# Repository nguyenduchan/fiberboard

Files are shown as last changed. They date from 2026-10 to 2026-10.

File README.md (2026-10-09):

# Fiberboard

Fiberboard là bo mạch điều khiển **logic tích hợp (AIO)**, không có driver stepper Nema. Dùng cho bơm DC, cấp liệu feeder, báo vật thể lạ và mini filler.

Trên bo có **đế cắm ESP32-DevKitC** (nạp phần mềm nhúng qua USB trên module). Nguồn vào **9–24 VDC**. Hai kênh quang **sợi POF 1 mm** (AFBR) gắn trên PCB. Đầu ra relay và van solenoid, **RS485**. Mỗi giắc vào/ra có **đèn SMD 0805** sát cọc. Trong cột nguồn có đèn debug: **D27** sáng khi +24 V sau bảo vệ còn điện, **D25** khi buck ra +5 V, **D6** khi LDO ra 3,3 V. Không có header OLED trên bo.

Kho mã này chỉ chứa thiết kế KiCad và script sinh mạch/layout. **Phần mềm nhúng (firmware)** không có trong kho.

Ghi chú thiết kế chi tiết: [`pcb/DESIGN_NOTES.txt`](pcb/DESIGN_NOTES.txt)

Khối **bảo vệ 24 V + buck** (dùng chung nhiều loại bo): [`pcb/PWR_24V_PROTECT_BUCK_GUIDE.txt`](pcb/PWR_24V_PROTECT_BUCK_GUIDE.txt)

---

## Chức năng các khối

| Khối | Mô tả |
|---|---|
| **MCU** | ESP32-DevKitC trên đế cắm; nạp firmware qua USB trên module |
| **Nguồn** | VIN → **F1/L2/RV1/D7/Q12/C4** → **XL1509** → **+5V**. Mỗi relay lấy +5 V qua ferrite riêng (FB4 / FB5). **AMS1117** → 3,3 V. Chỉ **một** cầu chì F1 tại nguồn tổng 24 V. Mass **NT1+D11+C23+FB3**. Chi tiết: [`pcb/PWR_24V_PROTECT_BUCK_GUIDE.txt`](pcb/PWR_24V_PROTECT_BUCK_GUIDE.txt) |
| **Quang 2 kênh** | Phát AFBR-1624Z + thu AFBR-2624Z mỗi kênh; sợi POF 1 mm cắm trên bo |
| **Đầu vào số** | FOOT (công tắc chân), NPN (cảm biến); cách ly quang PC817 |
| **Đầu ra** | 2 relay G6KU (COM/NO/NC) + 1 van solenoid (MOSFET 24 V); domino J5/J6/J7 (**2EDG5.08**, bước 5,08 mm); flyback D3/D4 (cuộn relay 5 V), D5 SS34 (solenoid trên J7); driver 2N3904 + AO3400A. Tiếp điểm relay kín — tải cảm lớn: snubber/diode tại tải hoặc theo catalog relay |
| **Giao tiếp** | RS485 bán song công (MAX485); **TVS D9/D10** + **R18/R19** trên A/B; LED trạng thái; I2C chỉ trên ESP32 |

Bảo vệ trên bo (tóm tắt): **F1** = đế cầu chì **5×20 mm có nắp** (chân 22,6 mm) tại nguồn tổng 24 V, ống sứ 4 A thay bằng tay, không PPTC SMD; **L2, RV1, D7, C4**; mass **NT1, D11, C23, FB3**; relay **D12/C24**; van lấy **+24V** sau F1. Đèn **Vào / Chì / 24V / 5V / 3V3** chỉ chỗ nguồn đứt. Đầu vào quang PC817; RS485 **D9/D10**. Lắp tủ: nguồn 24 V ≥ 1,5–2 A, dây xoắn, IEC 61000-6-2; dừng khẩn / SIL — phần cứng an toàn riêng.

---

## Đầu nối ra ngoài (I/O)

**Cạnh dài trên** (trái → phải): `J1 | J3 | J4 | F1T | F1R | F2T | F2R` — nguồn vào 24 V, chân, NPN, quang.

**Cạnh dài dưới** (trái → phải): `J5 | J6 | J7 | J2 | J8` — relay 1, relay 2, van, giắc 24 V ra cho bàn phím, rồi RS485. Các giắc giãn trên suốt cạnh; cột relay, van và RS485 rộng hơn để xếp linh kiện trong khung của cọc. Cột trái trong lòng là bảo vệ 24 V, cột kế là buck.

| Ref | Tên | Chân | Ý nghĩa |
|-----|-----|---|---|
| **J1** | VIN | 1 | +9 … +24 VDC |
| | | 2 | Mass domino nguồn |
| **F1T** | Quang 1 phát | POF | Phát; cắm sợi 1 mm thẳng vào mắt hướng ra cạnh bo |
| **F1R** | Quang 1 thu | POF | Thu kênh 1 (cùng chiều cắm như phát) |
| **F2T** | Quang 2 phát | POF | Phát kênh 2 |
| **F2R** | Quang 2 thu | POF | Thu kênh 2 |
| **J3** | FOOT | 1 | Cực A công tắc chân (qua opto) |
| | | 2 | Cực K / mass về |
| **J4** | NPN | 1 | V+ 24 V cho cảm biến hiện trường |
| | | 2 | SIG (tín hiệu NPN) |
| | | 3 | Mass hiện trường (GND_PWR) |
| **J5** | RELAY 1 | 1 / 2 / 3 | COM / NO / NC |
| **J6** | RELAY 2 | 1 / 2 / 3 | COM / NO / NC |
| **J7** | SOLENOID | 1 | +24 V (cực dương cuộn van) |
| | | 2 | SOL− (cực âm; bo cắt mass phía âm) |
| **J2** | Keyboard | 1 / 2 | +24 V đã qua F1 (cùng rail +24V) / mass nguồn. Cấp cho J_PWR mạch keyboard |
| **J8** | RS485 | 1 / 2 / 3 | A / B / mass logic (**2EDG5.08-3P** cái trên bo) |

### Domino hiện trường — **2EDG5.08** (dễ mua Shopee)

| Hạng mục | Khuyến nghị |
|---|---|
| **Trên PCB** | Socket **2EDG5.08** cái, chân ngang 5,08 mm (footprint `Fiberboard:Terminal_2EDG5.08-…`) |
| **Dây ra hiện trường** | **Đầu đực 2EDG** cùng bước (bộ **đực + cái** 2P/3P), siết dây vào đực; hoặc cáp **CH5.08** một đầu + đầu đực 2EDG tùy shop |
| **Tìm mua** | Shopee: `2EDG5.08 3P đực cái thẳng` · `2EDG5.08 2P` · `cáp CH5.08 3P 20cm` (đầu jack — thường gắn thêm đực 2EDG nếu cần) |

### RS485 (J8)

| Hạng mục | Khuyến nghị |
|---|---|
| **Cắm** | **2EDG5.08-3P** đực (giống J4–J6) |
| **Cáp** | Đôi xoắn **2×0,25–0,5 mm²** + bọc chắn; **A/B** chân 1–2, **mass** chân 3; bọc chắn nối mass **một đầu** |
| **Trên bo** | **R15 100 Ω** giữa A–B (điểm cuối bus — termination; gộp mã với R13) |
| **Bố trí** | **J8** ở **cạnh dài dưới** (cùng hàng relay/van), góc phải |

| Ref | Socket trên bo | Dây hiện trường (phổ biến VN) |
|-----|---|---|
| **J1, J3, J7** | 2EDG **2P** cái | Đực **2EDG5.08-2P** + dây 0,5–1,5 mm² |
| **J4, J5, J6, J8** | 2EDG **3P** cái | Đực **2EDG5.08-3P** (+ cáp xoắn có bọc cho RS485) |

Cột I/O tính theo **bề ngang cắm đực 2EDG**, xếp trên **cạnh dài** của hộp 145×90×40.

---

## GPIO ESP32 (tham chiếu firmware)

Tên tín hiệu trong firmware giữ nguyên; cột **Hướng** = vào/ra MCU.

| GPIO | Tín hiệu | Hướng | Ghi chú |
|---|---|---|---|
| IO32 | FIBER1_PWM | Ra | LEDC PWM → phát quang kênh 1 |
| IO33 | FIBER2_PWM | Ra | LEDC PWM → phát quang kênh 2 |
| IO4 | FIBER1_DIG | Vào | TTL từ thu quang kênh 1 |
| IO15 | FIBER2_DIG | Vào | TTL từ thu quang kênh 2 |
| IO25 | IN_FOOT | Vào | Công tắc chân (sau opto) |
| IO26 | IN_NPN | Vào | Cảm biến NPN (sau opto) |
| IO27 | OUT_RLY1 | Ra | Driver relay 1 |
| IO14 | OUT_RLY2 | Ra | Driver relay 2 |
| IO13 | OUT_MOS | Ra | Solenoid |
| IO16 | RS485_RX | Vào | UART RX (MAX485) |
| IO17 | RS485_DE | Ra | DE và RE# (MAX485) |
| IO23 | RS485_TX | Ra | UART TX |
| IO21 | I2C_SDA | Hai chiều | Không ra header bo (tùy chọn ngoài) |
| IO22 | I2C_SCL | Ra | Không ra header bo (tùy chọn ngoài) |

IO32, IO33, IO4, IO15, IO23 và IO16 có điện trở nối tiếp 1 kΩ (R40–R45) trước mắt quang và MAX485.

---

## Thư mục trong kho mã

| Đường dẫn | Vai trò |
|---|---|
| `pcb/fiberboard-logic.kicad_pro` | Dự án KiCad 10 (sơ đồ + PCB) |
| `pcb/DESIGN_NOTES.txt` | Ghi chú nguồn, layout, quang |
| `pcb/PWR_24V_PROTECT_BUCK_GUIDE.txt` | Hướng dẫn khối bảo vệ 24 V và buck (dùng chung) |
| `pcb/BOM.txt` | BOM đầy đủ + bảng **gộp mã** linh kiện cơ bản + giá VND |
| `pcb/ASSEMBLY.txt` | Vùng lắp ráp tùy chọn theo giắc (DNP cả nhóm) |
| `pcb/libraries/` | Symbol và footprint Fiberboard |
| `pcb/scripts/generate_kicad_project.py` | Sinh lại sơ đồ/PCB/thư viện |
| `pcb/scripts/connectivity.py` | Danh sách mạng và kết nối |
| `pcb/scripts/pcb_layout.py` | Vị trí footprint, silk I/O |
| `pcb/scripts/check_pcb_layout.py` | Kiểm tra chồng linh kiện sau khi sinh PCB |
| `pcb/scripts/autoroute.py` | Đi dây tự động (A* trên lưới 0,1 mm, 2 lớp; lõi tăng tốc bằng numba trong `maze_nb.py`): mọi chân ra thẳng ≥0,6 mm rồi mới rẽ; đi dây cả GND/GND_PWR; chân kẹt thì dịch nhẹ linh kiện thụ động (bước 0,25 mm, ≤3 mm, không tạo chồng courtyard mới) và rip-up net chắn đường. Chạy sau `generate_kicad_project.py`: `python pcb/scripts/autoroute.py --passes 7 --png route.png` (~5–6 phút) |

---

## Cách làm việc

| Bước | Việc cần làm |
|---|---|
| 1 | Mở `pcb/fiberboard-logic.kicad_pro` trong KiCad 10 |
| 2 | Sau khi sửa Python: `python pcb/scripts/generate_kicad_project.py` (cần KiCad 10; đường dẫn KiCad trong script) |
| 3 | Đi dây PCB theo ratsnest; refill pour **GND** và **GND_PWR** tại điểm sao **NT1** (cạnh C4) |
| 3b | Sau `generate_kicad_project.py`: `python pcb/scripts/check_pcb_layout.py` — kiểm tra chồng linh kiện. **DRC đỏ “unconnected”** là bình thường khi chưa đi dây (file sinh ra không có track) |

---

## Kích thước bo và vỏ

> **Vỏ:** hộp PLC **145 × 90 × 40 mm** (mã 145T-1D). Giắc nhà máy nằm trên **cạnh dài** (~20 vị trí, pitch 5 mm), không phải hai đầu 90 mm. Lòng thân khoảng **125 × 90 mm**. PCB **118 × 84 mm**.

| Hạng mục | Giá trị |
|---|---|
| **PCB** | 118 × 84 mm |
| **Vỏ** | Hộp PLC ABS 145 × 90 × 40 mm |
| **Giắc** | Cạnh dài trên: J1 nguồn vào, J3 chân, J4 NPN, quang. Cạnh dài dưới: J5/J6 relay, J7 van sát J2 (24 V ra bàn phím), J8 RS485 |
| **Lớp / độ dày** | 2 lớp FR4, 1,6 mm |
| **Lắp ráp** | SMD ưu tiên; domino và AFBR xuyên lỗ theo footprint |
| **Silk mép dưới** | Cột I/O: nhãn tiếng Việt sát giắc cắm, căn giữa ô; chỉnh trong `pcb/scripts/pcb_layout.py` → `IO_LABELS` |

### Ước giá linh kiện (tham chiếu)

Chi tiết từng mã: [`pcb/BOM.txt`](pcb/BOM.txt). Tóm tắt (lẻ VN, 1 bo):

| Hạng mục | Khoảng (k VND) |
|---|---|
| Linh kiện trên PCB (không gồm module ESP32) | ~530 – 1.060 |
| ESP32-DevKitC | ~90 – 185 |
| PCB 2 lớp 118×84 mm | ~25 – 120 |
| **Lắp đủ một máy** | **~645 – 1.365** |

Khối nguồn + cầu chì 5×20: ~165–300k (không relay). Quang AFBR và relay là hai khoản biến động lớn nhất.

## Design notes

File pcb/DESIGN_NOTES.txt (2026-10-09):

Fiberboard logic tích hợp — Ghi chú thiết kế (cấu hình cuối)
==============================================================

Biến thể: logic / feeder / báo / mini filler (không Nema). MCU: đế cắm ESP32-DevKitC-32E (U1, 38 chân).

Tài liệu nguồn + layout: pcb/PWR_24V_PROTECT_BUCK_GUIDE.txt
BOM đầy đủ + giá: pcb/BOM.txt
Lắp ráp DNP theo giắc: pcb/ASSEMBLY.txt

Nguồn và mass
-------------
- VIN J1 9–24 V → F1 (đế 5×20 có nắp, chân 22,6 mm, ống sứ 4 A thay tay) → L2 → RV1/D7 → Q12 → C4 → U2 buck → FB2/C22 → +5V
  → U3/FB1 → +3V3
- Điểm sao mass: NT1 (GND_PWR ↔ GND_SPLICE); D11 + C23; FB3 → GND logic
- Relay: mỗi cọc một group đủ mạch. J5 = FB4 → D12/C24/C25 → K1 (D3, Q3). J6 = FB5 → D26/C26/C27 → K2 (D4, Q4). Xóa một group không cắt nguồn relay còn lại hay phần còn lại của bo. Không cầu chì riêng trên cuộn
- Van: J7 lấy +24V sau F1 (flyback D5); Q5 cắt mass phía âm. Không cầu chì riêng trên van
- Không DC-DC cách ly; đầu vào quang PC817; RS485 TVS D9/D10, R18/R19

Pour mass (đồng)
----------------
- GND_PWR: cột trái (bảo vệ, buck) và giắc trên J1, J3, J4
- GND: cột MCU + hàng dưới bên phải (J2 cấp bàn phím, J5–J7, J8)
- Nối pour: chỉ NT1 (+ D11/C23/FB3 trên sơ đồ)

Layout PCB 118×84 mm (hộp PLC 145×90×40, giắc trên cạnh dài)
----------------------------------------------------------
- Cạnh dài trên: J1 nguồn vào 24 V, J3 chân, J4 NPN, rồi F1T/F1R, F2T/F2R
- Cạnh dài dưới, trái → phải: J5 relay 1, J6 relay 2, J7 van, J2 (24 V ra cho bàn phím), J8 RS485. Giắc giãn trên suốt cạnh; cột group đông linh kiện (relay, van, RS485, opto) rộng hơn cột cọc ít linh kiện.
- Trong lòng, trái → phải: cột **PWR_24V_PROTECT** (F1 đến sao mass, tụ C19/C15/C14 và R17 sát nút lọc) rồi cột **PWR_BUCK** (C16/C17 sát U2, C2/C5 sát ra 5 V, R36–R38 sát chân FB/EN).
- 145T-1D là lỗ 1 phía (khoảng 20P trên một cạnh dài). Hàng ra ở cạnh dài đối diện cần bản lỗ 2 phía hoặc khoét thêm.

I/O
---
- Relay G6KU J5/J6; solenoid J7; FOOT/NPN J3/J4 (opto); RS485 J8 2EDG5.08
- Quang 2 kênh AFBR trên bo; sợi POF 1 mm; C12/C13 lọc nguồn cục bộ
- Flyback: D3/D4 relay 5 V; D5 solenoid 24 V
- Đèn SMD 0805 sát giắc, không thêm GPIO. Nhãn in trên bo: D13 Vào (có điện J1, trước cầu chì); D28 Chì (ngay sau cầu chì, trước L2/Q12); D14 KB (+24 V ra J2); D15 Chân; D16 NPN; D17 RL1; D18 RL2; D19 Van; D20 485; D21–D24 TX1/RX1/TX2/RX2. Debug nguồn trong cột nguồn, nhãn in: D27 24V (sau Q12/C4) tắt thì lỗi trước buck; D25 5V (+5V_RAW cạnh C2) tắt thì buck không ra; D6 3V3 tắt thì LDO không ra. Đọc lỗi nguồn: Vào tắt = mất điện hoặc cắm ngược; Vào sáng + Chì tắt = cầu chì đứt; Chì sáng + 24V tắt = Q12 không thông; 24V sáng + 5V tắt = buck; 5V sáng + 3V3 tắt = LDO. Trở 1 kΩ ở 3,3 V/5 V; 10 kΩ ở 24 V.

GPIO (ESP32)
------------
IO32/33 PWM quang | IO4/15 số | IO25 FOOT | IO26 NPN
IO27/14 relay | IO13 solenoid | IO16/17/23 RS485 | IO21/22 I2C (không header OLED)

Quang 2 kênh (POF 1 mm)
-----------------------
- Phát AFBR-1624Z (F1T/F2T) và thu AFBR-2624Z (F1R/F2R) cùng cạnh dài trên
- IO32/IO33 LEDC → R40/R41 → DATA_IN phát | DATA_OUT thu → R42/R43 → IO4/IO15. IO23/IO16 qua R44/R45 tới DI/RO MAX485.
- C12/C13 100 nF mỗi kênh; không kẹp J2/J11; không khuếch đại ngoài

PCB / vỏ / gia công
-------------------
- Edge.Cuts 118×84 mm (vỏ 145×90×40, lòng thân ~125×90; giắc dọc cạnh 145 mm)
- 2 lớp FR4 1,6 mm; sâu hộp 40 mm — kiểm tra đế + DevKitC không chạm nắp
- Nhãn giắc (tên cổng và chân) và nhãn ý nghĩa đèn in trên F.SilkS. Nhãn nhóm, R/C, MOS, DIN nằm trên F.Fab (thấy trong KiCad, không in). Điện trở hiện "R" + trị số, tụ hiện "C" + trị số trên F.Fab. Nút anode đèn đặt tên *_AN.

Quy trình
---------
1. pcb/fiberboard-logic.kicad_pro
2. python pcb/scripts/generate_kicad_project.py (sau khi sửa script)
3. python pcb/scripts/check_pcb_layout.py
4. Đi dây ratsnest; refill GND / GND_PWR tại NT1 (DRC unconnected trước khi đi dây là bình thường)

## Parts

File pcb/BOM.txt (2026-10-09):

Fiberboard logic — BOM đầy đủ (1 bo)
=====================================
Nguồn sơ đồ: pcb/scripts/connectivity.py | Cập nhật theo đế cầu chì 5×20 có nắp, ống sứ.
Giá VND: lẻ Shopee / LCSC VN, một bộ (±30%), chưa VAT, chưa phí ship. Không gồm ESP32-DevKitC (cắm U1), nguồn 24 V ngoài, dây field, vỏ tủ, gia công PCB/SMT.

Bộ linh kiện cơ bản gộp mã (mua theo cuộn / lốc)
------------------------------------------------
Mục tiêu: hàn tay / SMT lô nhỏ với ít mã SMD thụ động. Số lượng ≈ cho 1 bo (+ dự phòng nhỏ).

| Mã gộp | Giá trị / loại | Số lượng | Ref tiêu biểu | Không gộp được (giữ riêng) |
|---|---|---|---|---|
| R-1k | 1 kΩ 0805 | 22 | R7,R8,R11,R12,R16,R24–R27,R29–R34,R37,R40–R45 | Đèn 3,3 V/5 V, kênh logic, nối tiếp GPIO |
| R-10k | 10 kΩ 0805 | 9 | R9,R10,R14,R22,R23,R28,R38,R39,R46 | R22/R23/R28/R39/R46 đèn 24 V |
| R-100 | 100 Ω 0805 | 2 | R13,R15 | R15: termination RS485 ngắn (≈120 Ω → 100 Ω) |
| R-10 | 10 Ω 0805 | 2 | R18,R19 | RS485 series |
| R-100k | 100 kΩ 0805 | 1 | R17 | Cổng Q12 |
| R-3k | 3 kΩ 0805 | 1 | R36 | FB XL1509 — không đổi |
| C-100n | 100 nF 0805 | 14 | C5,C12–C18,C21,C23,C25,C27 | Gồm C23 ‖ D11; C25/C27 lọc từng relay |
| C-10u25 | 10 µF 0805 ≥25 V | 3 | C16,C19,C7 | Vin 24 V / buck / LDO in |
| C-22u10 | 22 µF 0805 ≥10 V | 1 | C3 | Ra AMS1117 (datasheet) |
| C-elec220 | 220 µF 6,3–10 V radial SMD | 4 | C2,C22,C24,C26 | C24 relay 1, C26 relay 2 |
| C-elec1000 | 1000 µF 25 V | 1 | C4 | |
| D-SS34 | SS34 SOD-123 | 4 | D3,D4,D5,D8 | Flyback + buck |
| D-TVS28 | SMAJ28A SMA | 1 | D7 | VIN |
| D-TVS5 | SMAJ5.0A SMA | 5 | D9–D12,D26 | D12 relay 1, D26 relay 2, RS485, mass |
| FB-BLM | BLM21PG121 0805 | 5 | FB1–FB5 | FB4 relay 1, FB5 relay 2 |
| Q-2N3904 | 2N3904 SOT-23 | 2 | Q3,Q4 | |
| Fuse-holder | Đế 5×20 có nắp, chân 22,6 mm | 1 | F1 | Chỉ nguồn tổng 24 V |
| Fuse-tube | ống sứ 5×20 4 A | 1 | F1 | Thủy tinh F4A lắp được cùng đế |

IC / cơ khí / quang: XL1509, AMS1117, AO4407A, AO3400A, MAX485, PC817×2, G6KU×2, ACM2012, MOV, domino 2EDG, AFBR×4, giá ESP32 — mỗi loại một mã.

Đã chỉnh sơ đồ (connectivity.py) để khớp bảng gộp mã ở trên.

Tóm tắt theo khối
----------------
| Khối | Số dòng linh kiện (loại) | Thấp (k) | Cao (k) |
|---|---|---|---|
| PWR_24V_PROTECT | 16 | 46 | 88 |
| PWR_BUCK | 23 | 53 | 91 |
| J5 + J6 + J7 | 14 | 65 | 120 |
| MCU (chỉ socket U1) | 1 | 18 | 40 |
| Quang 2 kênh | 6 | 220 | 480 |
| Đầu vào FOOT/NPN | 8 | 25 | 45 |
| Relay + domino J5/J6 | 8 | 55 | 100 |
| Solenoid + J7 | 7 | 20 | 38 |
| RS485 + LED + J8 | 8 | 22 | 42 |
| Domino còn lại (J1,J3) | 2 | 6 | 14 |
| **Tổng linh kiện trên PCB** | **~90 chỗ hàn** | **~531** | **~1.063** |
| ESP32-DevKitC (lắp socket, mua riêng) | 1 | 90 | 185 |
| PCB 2L 172×98 mm (5–10 bo) | 1 | 25 | 120 |
| **Tổng lắp 1 máy (có DevKit, có PCB)** | | **~646** | **~1.368** |

Nguồn 24 V ≥ 1,5–2 A (tủ): 150–400k. Ống sứ 5×20 4 A dự phòng (chỉ F1): ~8–20k.

Bảng chi tiết — Nguồn vào & bảo vệ (PWR_24V_PROTECT)
----------------------------------------------------
| Qty | Ref | Giá trị | Footprint / loại | Thấp | Cao | Ghi chú |
|-----|-----|---|---|---|-----|---|
| 1 | J1 | VIN 2EDG5.08-2P | Terminal_2EDG 2P | 3.000 | 8.000 | Socket cái trên bo |
| 1 | F1 | Đế 5×20 có nắp + ống sứ 4 A | Fuseholder_5x20mm_Covered | 8.000 | 18.000 | Đế chân 22,6 mm 5–12k + ống sứ 2–6k |
| 1 | R46 | 10 kΩ | 0805 | 200 | 500 | Đèn Chì, sau cầu chì (gộp R-10k) |
| 1 | D28 | LED Chì | LED 0805 | 500 | 2.000 | Sáng khi còn điện ngay sau F1; tắt trong khi Vào sáng thì cầu chì đứt |
| 1 | L2 | ACM2012 | CM 4 chân SMD | 4.000 | 10.000 | Lọc nhiễu chung |
| 1 | RV1 | MOV ~26 V | Varistor VF | 2.000 | 6.000 | |
| 1 | D7 | SMAJ28A | D_SMA | 1.000 | 3.000 | TVS VIN |
| 1 | C19 | 10 µF 25 V | 0805 | 300 | 1.200 | |
| 1 | C15 | 100 nF | 0805 | 200 | 600 | |
| 1 | Q12 | AO4407A | SOT-23 | 2.000 | 6.000 | P-FET chống ngược |
| 1 | R17 | 100 kΩ | 0805 | 200 | 500 | Cổng Q12 |
| 1 | C4 | 1000 µF 25 V | CP_Elec 10×12,5 | 8.000 | 18.000 | Bulk |
| 1 | C14 | 100 nF | 0805 | 200 | 600 | |
| 1 | R39 | 10 kΩ | 0805 | 200 | 500 | Đèn debug +24 V (gộp R-10k) |
| 1 | D27 | LED 24V | LED 0805 | 500 | 2.000 | Sáng khi +24 V sau bảo vệ còn điện |
| 1 | NT1 | GND_STAR | NetTie-2 SMD | 0 | 1.000 | Pad nối mass |
| 1 | D11 | SMAJ5.0A | D_SMA | 1.000 | 3.000 | Mass GND_PWR↔splice |
| 1 | C23 | 100 nF | 0805 | 200 | 600 | ‖ D11 (gộp mã C-100n) |
| 1 | FB3 | BLM21PG121 | 0805 | 800 | 2.500 | Mass → logic |

Bảng chi tiết — Buck, LDO, nhánh relay (PWR_BUCK)
-------------------------------------------------
| Qty | Ref | Giá trị | Footprint | Thấp | Cao | Ghi chú |
|-----|-----|---|---|---|-----|---|
| 1 | U2 | XL1509-5.0 | TO-263-5 | 8.000 | 18.000 | Buck 24→5 V |
| 1 | C16 | 10 µF | 0805 | 300 | 1.000 | Vin buck |
| 1 | C17 | 100 nF | 0805 | 200 | 600 | |
| 1 | D8 | SS34 | SOD-123 | 400 | 1.200 | |
| 1 | L1 | 47 µH | 1210 | 4.000 | 12.000 | |
| 1 | C2 | 220 µF 6,3–10 V | CP_Elec 6,3×5,4 | 4.000 | 10.000 | Ra buck |
| 1 | C5 | 100 nF | 0805 | 200 | 600 | |
| 1 | R34 | 1 kΩ | 0805 | 200 | 500 | Đèn debug +5V_RAW |
| 1 | D25 | LED 5V | LED 0805 | 500 | 2.000 | Sáng khi buck ra 5 V; tắt thì buck lỗi |
| 1 | R36 | 3 kΩ | 0805 | 200 | 500 | FB U2 |
| 1 | R37 | 1 kΩ | 0805 | 200 | 500 | |
| 1 | R38 | 10 kΩ | 0805 | 200 | 500 | EN |
| 1 | FB2 | BLM21PG121 | 0805 | 800 | 2.500 | +5V_RAW→+5V |
| 1 | C22 | 220 µF | CP_Elec 6,3×5,4 | 4.000 | 10.000 | Rail +5V |
| 1 | U3 | AMS1117-3.3 | SOT-223 | 2.000 | 6.000 | 3,3 V |
| 1 | R16 | 1 kΩ | 0805 | 200 | 500 | Đèn debug +3V3 |
| 1 | D6 | LED 3V3 | LED 0805 | 500 | 2.000 | Sáng khi LDO ra 3,3 V; tắt trong khi D25 sáng thì lỗi LDO |
| 1 | C7 | 10 µF | 0805 | 300 | 1.000 | |
| 1 | C3 | 22 µF | 0805 | 400 | 1.500 | |
| 1 | C18 | 100 nF | 0805 | 200 | 600 | |
| 1 | FB1 | BLM21PG121 | 0805 | 800 | 2.500 | +3V3 |
| 1 | C21 | 100 nF | 0805 | 200 | 600 | |

Dòng tóm tắt PWR_BUCK vẫn tính FB4, D12, C24, C25. Trên bo các ref đó thuộc group J5.

Bảng chi tiết — J5 relay 1 (OPT_J5_RLY1)
------------------------------------------
| Qty | Ref | Giá trị | Footprint | Thấp | Cao | Ghi chú |
|-----|-----|---|---|---|-----|---|
| 1 | J5 | RLY1 2EDG 3P | Terminal 3P | 4.000 | 9.000 | |
| 1 | K1 | G6KU-2F-Y | G6KU-2F_SMD | 22.000 | 45.000 | Relay 1 |
| 1 | Q3 | 2N3904 | SOT-23 | 300 | 800 | Driver K1 |
| 1 | D3 | SS34 | SOD-123 | 400 | 1.200 | Flyback K1 (gộp D-SS34) |
| 1 | R11 | 1 kΩ | 0805 | 200 | 500 | |
| 1 | FB4 | BLM21PG121 | 0805 | 800 | 2.500 | Nhánh +5V_RLY1 |
| 1 | D12 | SMAJ5.0A | D_SMA | 1.000 | 3.000 | TVS nhánh J5 |
| 1 | C24 | 220 µF 6,3–10 V | CP_Elec 6,3×5,4 | 4.000 | 10.000 | Cùng mã C2/C22 |
| 1 | C25 | 100 nF | 0805 | 200 | 600 | |

Bảng chi tiết — J6 relay 2 (OPT_J6_RLY2)
------------------------------------------
| Qty | Ref | Giá trị | Footprint | Thấp | Cao | Ghi chú |
|-----|-----|---|---|---|-----|---|
| 1 | J6 | RLY2 2EDG 3P | Terminal 3P | 4.000 | 9.000 | |
| 1 | K2 | G6KU-2F-Y | G6KU-2F_SMD | 22.000 | 45.000 | Relay 2 |
| 1 | Q4 | 2N3904 | SOT-23 | 300 | 800 | Driver K2 |
| 1 | D4 | SS34 | SOD-123 | 400 | 1.200 | Flyback K2 |
| 1 | R12 | 1 kΩ | 0805 | 200 | 500 | |
| 1 | FB5 | BLM21PG121 | 0805 | 800 | 2.500 | Nhánh +5V_RLY2, cùng đơn giá FB4 |
| 1 | D26 | SMAJ5.0A | D_SMA | 1.000 | 3.000 | TVS nhánh J6, cùng đơn giá D12 |
| 1 | C26 | 220 µF 6,3–10 V | CP_Elec 6,3×5,4 | 4.000 | 10.000 | Cùng mã C24 |
| 1 | C27 | 100 nF | 0805 | 200 | 600 | Cùng mã C25 |

Bảng chi tiết — J7 van (OPT_J7_SOL)
------------------------------------
| Qty | Ref | Giá trị | Footprint | Thấp | Cao | Ghi chú |
|-----|-----|---|---|---|-----|---|
| 1 | J7 | SOL 2EDG 2P | Terminal 2P | 3.000 | 8.000 | |
| 1 | Q5 | AO3400A | SOT-23 | 1.000 | 3.000 | Van |
| 1 | D5 | SS34 | D_SMA | 800 | 2.000 | Flyback van |
| 1 | R13 | 100 Ω | 0805 | 200 | 500 | Cổng Q5 |
| 1 | R14 | 10 kΩ | 0805 | 200 | 500 | Kéo xuống | |

Bảng chi tiết — MCU, quang, tín hiệu (MCU_SIGNAL)
-------------------------------------------------
| Qty | Ref | Giá trị | Footprint | Thấp | Cao | Ghi chú |
|-----|-----|---|---|---|-----|---|
| 1 | U1 | ESP32-DevKitC socket | ESP32_DevKitC_Socket | 18.000 | 40.000 | Chỉ đế; module riêng |
| 1 | R20 | 100 kΩ | 0805 | 200 | 500 | CORE_MCU — kéo IN_FOOT khi không opto J3 |
| 1 | R21 | 100 kΩ | 0805 | 200 | 500 | CORE_MCU — kéo IN_NPN khi không opto J4 |
| 1 | F1T | AFBR-1624Z | AFBR_1624Z_VL | 55.000 | 130.000 | Phát kênh 1 |
| 1 | F1R | AFBR-2624Z | AFBR_2624Z_VL | 55.000 | 130.000 | Thu kênh 1 |
| 1 | F2T | AFBR-1624Z | AFBR_1624Z_VL | 55.000 | 130.000 | Phát kênh 2 |
| 1 | F2R | AFBR-2624Z | AFBR_2624Z_VL | 55.000 | 130.000 | Thu kênh 2 |
| 1 | C12 | 100 nF | 0805 | 200 | 600 | Decap kênh 1 |
| 1 | C13 | 100 nF | 0805 | 200 | 600 | Decap kênh 2 |
| 1 | J3 | FOOT 2EDG 2P | Terminal 2P | 3.000 | 8.000 | |
| 1 | U5 | PC817 | PC817_SO4 | 1.500 | 4.000 | |
| 1 | R7 | 1 kΩ | 0805 | 200 | 500 | |
| 1 | R9 | 10 kΩ | 0805 | 200 | 500 | |
| 1 | J4 | NPN 2EDG 3P | Terminal 3P | 4.000 | 9.000 | |
| 1 | U6 | PC817 | PC817_SO4 | 1.500 | 4.000 | |
| 1 | R8 | 1 kΩ | 0805 | 200 | 500 | |
| 1 | R10 | 10 kΩ | 0805 | 200 | 500 | |
| 1 | U7 | MAX485E | SOIC-8 | 8.000 | 18.000 | |
| 1 | R15 | 100 Ω | 0805 | 200 | 500 | Termination A–B (gộp R-100) |
| 1 | R18 | 10 Ω | 0805 | 200 | 500 | |
| 1 | R19 | 10 Ω | 0805 | 200 | 500 | |
| 1 | D9 | SMAJ5.0A | D_SMA | 1.000 | 3.000 | TVS A (gộp D-TVS5) |
| 1 | D10 | SMAJ5.0A | D_SMA | 1.000 | 3.000 | TVS B |
| 1 | J8 | RS485 2EDG 3P | Terminal 3P | 4.000 | 9.000 | |
| 12 | D13–D24 | LED 0805 | LED_0805 | 500 | 2.000 | Sát giắc J1–J8 và 4 mắt quang; cùng đơn giá D6 |

Linh kiện không hàn (mua kèm khi lắp máy)
-----------------------------------------
| Qty | Mô tả | Thấp | Cao |
|-----|---|---|-----|
| 1 | ESP32-DevKitC-32E (cắm U1) | 90.000 | 185.000 | 38 chân, WROOM-32E, USB trên module |
| 1 | Nguồn 24 VDC 1,5–2 A DIN | 150.000 | 400.000 | Tủ điện |
| 2 | Ống sứ 5×20 4 A dự phòng | 4.000 | 16.000 | Chỉ F1; F4A thủy tinh lắp tạm được |
| 8 | Đầu đực 2EDG field | 20.000 | 50.000 | Theo J1–J8 |
| 2 | Sợi POF 1 mm (tùy chiều dài) | 10.000 | 40.000 | Quang |

Ghi chú đặt hàng
----------------
- SMD 0805/1206, SOIC, SOT: có thể dùng bộ linh kiện rời hoặc SMT JLC (chưa tính trong bảng trên).
- AFBR: giá biến động mạnh; có thể thay footprint tương thích 1629Z/2529Z nếu shop có.
- Tổng **chỉ linh kiện bo** (không DevKit, không PCB): cộng cột Thấp/Cao bảng chi tiết ≈ **531k–1.063k VND**, chưa gồm 12 đèn giắc mới. 12 LED đó cùng đơn giá D6 (0,5–2k) và trở 1 kΩ/10 kΩ đã có trong bảng gộp: thêm khoảng **8k–30k**. D27/R39 debug +24 V nằm trong bảng bảo vệ (0,7–2,5k, đã cộng vào tổng). R40–R45 (6×1 kΩ, cùng đơn giá 200–500) thêm khoảng **1,2–3k**, đã nằm trong dòng R-1k.
- Khối nguồn (protect + buck): ≈ **165k–300k VND** kể cả FB4/D12/C24 từng nằm trong dòng buck. Relay và van tính ở group J5, J6, J7.

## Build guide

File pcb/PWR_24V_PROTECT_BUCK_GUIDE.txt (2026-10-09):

Cấu hình nguồn 24 V + buck + công suất + mass (Fiberboard và tái sử dụng)
===========================================================================
Phiên bản: Fiberboard logic — mức 1 (lọc CM/MOV/tụ giữ áp, không DC-DC cách ly).
Nguồn vào domino 9–24 VDC. Nguồn ngoài: 24 VDC ≥ 1,5–2 A (ray DIN công nghiệp).
Danh sách mạng: pcb/scripts/connectivity.py | Bố trí: pcb/scripts/pcb_layout.py

0. Yêu cầu môi trường (máy dập / băng chuyền) — cấu hình áp dụng
-----------------------------------------------------------------
| Hạng mục | Cấu hình trên bo / tủ |
|---|---|
| Nguồn vào | 9–24 VDC qua J1; nguồn 24 V ≥ 1,5–2 A, có bảo vệ quá dòng |
| Xung nhiễu VIN | F1 đế 5×20 có nắp + ống sứ 4 A (thay tay), L2 lọc CM, RV1 MOV, D7 TVS, C19/C15 tần số cao, Q12 chống ngược, C4 1000 µF giữ áp |
| Mass | Tách GND_PWR / GND logic; nối sao NT1 + D11 ‖ C23 + FB3 (không nhánh mass song song dọc bo) |
| Buck / logic | XL1509 + ferrite FB2; AMS1117 + FB1; không đi dây SW/L1 dưới ESP32 |
| Đầu ra công suất | Mỗi relay một nhánh +5 V (J5: FB4/D12/C24/C25, J6: FB5/D26/C26/C27); van lấy +24V sau F1; flyback D3/D4/D5 |
| Đầu vào hiện trường | Opto PC817 FOOT/NPN (không nối trực tiếp 24 V vào GPIO) |
| RS485 | TVS D9/D10 SMAJ5.0A trên A/B; R15 100 Ω; cáp xoắt + mass; bọc chắn một đầu |
| Vỏ / lắp | Hộp PLC ~179×100×48 mm; PCB 172×98 mm; dây nguồn xoắn; tách cáp motor/biến tần |
| Tham chiếu EMI | IEC 61000-6-2 (bố trí dây, đất vỏ, nguồn) |
| An toàn chức năng | Dừng khẩn, cửa, SIL/PL — phần cứng an toàn riêng (ISO 13849, IEC 60204-1); bo chỉ logic |
| Không có | DC-DC cách ly VIN; không snubber relay trên bo (tải cảm lớn: xử lý tại tải) |

1. Sơ đồ khối điện
------------------
  J1 VIN+ / VIN-
    → F1 đế cầu chì 5×20 mm có nắp (chân 22,6 mm; ống sứ 4 A, thay bằng tay)
    → L2 lọc CM (V+ và mass về domino)
    → RV1 MOV ‖ D7 TVS ‖ C19 (+ C15 tần số cao)
    → Q12 P-FET chống ngược
    → C4 1000 µF 25 V (+ C14 tần số cao)
    → U2 XL1509 → +5V_RAW → FB2 → +5V (+ C22)
    → U3 AMS1117 → FB1 → +3V3

  Mass:
    GND_PWR: mass về domino, buck, cực âm bulk C4, driver relay/van, mass +5V_RLY (cực âm D12)
    GND logic: ESP32, opto, IC RS485, tụ rail logic
    NT1 chân 1 = GND_PWR; NT1 chân 2 = GND_SPLICE
    D11 TVS ‖ C23 100nF: GND_PWR ↔ GND_SPLICE
    FB3: GND_SPLICE → GND (logic)

  Nhánh công suất (dòng nhỏ):
    +5V → FB4 → nhánh J5 (D12, C24/C25, K1)
    +5V → FB5 → nhánh J6 (D26, C26/C27, K2)
    +24V (sau F1) → J7 van (+ D5 flyback)

  Không thuộc khối nguồn (trên bo I/O): opto PC817, TVS RS485 D9/D10, flyback D3/D4 relay.

2. Layout PCB — thứ tự cột (trái → phải)
----------------------------------------
  | PWR_24V_PROTECT | PWR_BUCK | MCU_SIGNAL |

  Cột bảo vệ — hai ô silk, một nhóm KiCad PWR_24V_PROTECT:
    Lọc 24V vào:     F1, L2, Q12, RV1, D7, C19, C15, R17
    Bulk / nối mass*: C4, C14, NT1, D11, C23, FB3

  PWR_BUCK:        U2, L1, D8, C2, C22, U3, C16/C17, C7/C3, FB2, FB1, R36–R38, C5/C18/C21
  Giắc (không còn cột công suất): J5 = FB4, D12, C24/C25, K1 + driver; J6 = FB5, D26, C26/C27, K2 + driver; J7 = Q5 + D5
  MCU_SIGNAL:      U1, U7, U5/U6, linh kiện thụ động RS485, C12/C13
  Đèn debug nguồn: D27 trong cột bảo vệ (+24 V); D25 và D6 trong cột buck (+5V_RAW, +3V3)

  Pour đồng:
    GND_PWR: cột trái đến trước MCU_SIGNAL (bảo vệ + buck) + dải dưới J1/J5–J7
    GND:     cột MCU_SIGNAL + I/O phải (từ LOGIC_X0)
    Nối GND_PWR ↔ GND logic: chỉ tại NT1 (+ D11/C23/FB3 trên mạch sao)

  PCB Fiberboard: 172×98 mm; hàng domino mép dưới: J1 J5 J6 J7 | F1T–F2R J3 J4 J8.

  Thông số script pcb_layout.py (cột bên trong, mm):
    BOARD_W×BOARD_H = 172×98; DIN_RAIL_INSET = 3; INTERIOR_COL_GAP = 1
    PROTECT_COL_W = 34 | BUCK_COL_W = 36 | PWR_OUT_COL_W = 41
    LOGIC_X0 = mép trái cột MCU_SIGNAL; POWER_ZONE_W = LOGIC_X0 − XI0 (pour GND_PWR)
    GROUP_ALIAS: PWR_24V_PROTECT_IN / PWR_24V_PROTECT_BULK → PWR_24V_PROTECT
    Ô silk trong bảo vệ: ~38% chiều cao (vào) / ~48% (bulk/nối mass*)
    FRONT_IO_SPLIT ≈ 66 mm giữa domino nguồn/công suất (J1–J7) và I/O tín hiệu (phải)

2b. I/O tín hiệu và bảo vệ (MCU_SIGNAL — connectivity.py)
---------------------------------------------------------
| Chức năng | Linh kiện / quy tắc |
|---|---|
| FOOT / NPN | U5/U6 PC817; GPIO sau opto IO25/IO26 |
| Driver relay | Q3/Q4 2N3904; cuộn từ +5V_RLY; D3/D4 flyback |
| Solenoid | Q5 AO3400A cắt mass phía âm; J7-1 +24V (sau F1); D5 flyback |
| RS485 | U7 MAX485; D9/D10 SMAJ5.0A; R18/R19; R15 100 Ω; DE/RE IO17 |
| Quang 2 kênh | AFBR-1624Z phát / AFBR-2624Z thu; C12/C13 100 nF/kênh; IO32/33 PWM, IO4/15 số |
| Trạng thái | LED SMD 0805 tại mỗi giắc vào/ra, nhãn in trên bo; D28 Chì sau cầu chì; D27/D25/D6 debug nguồn (24V/5V/3V3) trong cột bảo vệ và buck; không header OLED trên bo |

3. Danh sách linh kiện — bảo vệ 24 V (PWR_24V_PROTECT)
------------------------------------------------------
| Ref | Giá trị | Footprint / ghi chú |
|-----|---|---|
| F1  | Đế 5×20 có nắp + sứ 4 A | Footprint Fuseholder_5x20mm_Covered; chân 22,6 mm; ống sứ nhanh 4 A (thủy tinh F4A lắp được cùng đế) |
| D28 | LED Chì | 0805, sáng khi còn điện ngay sau F1 |
| R46 | 10 kΩ | Hạn dòng D28 |
| L2  | CM ACM2012 | 4 chân, lọc CM |
| RV1 | MOV ~26 V | Varistor VF |
| D7  | TVS SMAJ28A | SMA |
| C19 | 10 µF 25 V | 0805 |
| C15 | 100 nF | 0805 |
| Q12 | AO4407A | SOT-23, high-side |
| R17 | 100 kΩ | 0805, cổng Q12 |
| C4  | 1000 µF 25 V | CP_Elec 10×12,5 |
| C14 | 100 nF | 0805 |
| NT1 | NetTie 2 | Pad1 GND_PWR |
| D11 | TVS SMAJ5.0A | GND_PWR ↔ GND_SPLICE |
| C23 | 100 nF | 0805, song song D11 (gộp mã 100 nF) |
| FB3 | BLM21PG121 | GND_SPLICE → GND logic |

4. Danh sách linh kiện — buck và LDO (PWR_BUCK)
-----------------------------------------------
| Ref  | Giá trị | Ghi chú |
|---|---|---|
| U2 | XL1509-5.0 | TO-263-5; Vin 8–40 V |
| C16  | 10 µF | Vin buck |
| C17  | 100 nF | Vin buck |
| D8 | SS34 | SW → GND_PWR |
| L1 | 47 µH | 1210 |
| C2 | 220 µF 6,3–10 V | Đầu ra buck |
| C5 | 100 nF | Tần số cao 5 V thô |
| R36  | 3 kΩ | FB (XL1509-5.0 cố định 5 V) |
| R37  | 1 kΩ | FB → GND_PWR |
| R38  | 10 kΩ | Kéo EN lên Vin |
| FB2  | BLM21PG121 | +5V_RAW → +5V |
| C22  | 220 µF 6,3–10 V | Sau FB2, rail +5V logic |
| FB4  | BLM21PG121 | +5V → nhánh J5 (đặt tại group J5) |
| U3 | AMS1117-3.3 | SOT-223 |
| C7 | 10 µF | Vào LDO |
| C3 | 22 µF | 3,3 V |
| C18  | 100 nF | Tần số cao 3,3 V |
| FB1  | BLM21PG121 | +3V3 |
| C21  | 100 nF | Sau FB1 |

5. Danh sách linh kiện — theo giắc công suất
--------------------------------------------
Không có group PWR_24V_OUT. Mỗi giắc một group.

J5 (OPT_J5_RLY1): FB4, D12 SMAJ5.0A, C24 220 µF, C25 100 nF, K1, Q3, D3, R11
J6 (OPT_J6_RLY2): FB5, D26 SMAJ5.0A, C26 220 µF, C27 100 nF, K2, Q4, D4, R12
J7 (OPT_J7_SOL):  Q5 AO3400A, D5 SS34, R13 100 Ω, R14 10 kΩ

6. Mạng (net) tham chiếu
------------------------
Tên mạng giữ nguyên trong KiCad; mô tả kết nối:

VIN_RAW:      J1-1 → F1-1
VIN_CM_IN:    F1-2 → L2-1
VIN_CM_RET:   J1-2 → L2-3
VIN_FUSE:     L2-2, D7-1, RV1-1, Q12-2, C15-1, C19-1
GND_PWR:      L2-4, D7-2, RV1-2, C19-2, C15-2, C14-2, C4-2, NT1-1, D11-1, C23-1,
              U2-5, D8-2, mass về buck/LDO công suất, Q3/Q4/Q5 driver, J4-3, D12-2, C24-2, C25-2
GND_SPLICE:   NT1-2, D11-2, C23-2, FB3-1
GND:          FB3-2, MCU, opto, RS485, phía logic C2/C22, tụ +3V3
+24V:         Q12-3, C4-1, C14-1, U2-1, C16/C17, R38, J2-1, J7-1, D5-1 (katốt flyback)
+5V_RAW:      L1-2, C2, C5, FB2-1
+5V:          FB2-2, C22, vào U3, ESP32-19, U7-8, phát quang, FB4-1
+5V_RLY1:    FB4-2, D12, C24/C25, cuộn+ K1, katốt D3
+5V_RLY2:    FB5-2, D26, C26/C27, cuộn+ K2, katốt D4
+3V3:         FB1-2, C21, ESP32, kéo lên opto

7. Quy tắc đi dây PCB
---------------------
- Vòng buck (U2, L1, D8, C2) gọn trong cột PWR_BUCK; không đi SW/L1 dưới hoặc song song U1.
- +5V logic và +5V_RLY: nhánh tách tại FB4; relay không dùng trace +5V chung dài với ESP32.
- Mass về driver relay/van: GND_PWR, đường ngắn trong khung của giắc J5, J6 hoặc J7.
- NT1, D11, C23, FB3: bố trí trong ô bulk/nối mass*; không thêm via nối GND_PWR–GND dọc ranh giới MCU.
- RS485 A/B: đôi xoắt; mass J8; bọc chắn một đầu; không chạy sát cuộn relay tại J5/J6.
- Refill pour GND / GND_PWR sau đi dây; điểm sao duy nhất tại NT1.

8. Cầu chì thay tay (chỉ F1 tại nguồn tổng 24 V)
-----------------------------------------------
- Một đế cầu chì ống **5×20 mm có nắp** gắn PCB, ngay sau J1 (footprint `Fiberboard:Fuseholder_5x20mm_Covered`, chân cách **22,6 mm**). Cao có nắp khoảng 20 mm — vừa hộp 40 mm.
- Mua đế: Shopee `đế cầu chì 5x20 có nắp 22.6` (kiểu PTF-15 / BLX-A có nắp). Đế kẹp hở không dùng.
- Ống: sứ **5×20 4 A nhanh** (Shopee `cầu chì sứ 5x20 4A`). Hết sứ thì ống thủy tinh F4A vẫn lắp cùng đế; nắp mới là thứ giữ ống khi rung.
- Khi đứt: chỉ thay ống; **không** thay PPTC SMD, không hàn lại mạch.
- Không có cầu chì riêng cho relay hay van. Relay và van nằm sau F1.

9. Lắp tủ
---------
- Dây nguồn 24 V xoắn; tách cáp motor/biến tần khỏi domino tín hiệu.
- Vỏ kim loại: nối đất một điểm với GND_PWR (nếu dùng).
- Tham chiếu bố trí EMI: IEC 61000-6-2.
- Dừng khẩn / cửa / SIL: phần cứng an toàn riêng (ISO 13849, IEC 60204-1); bo này chỉ logic.

10. Giá linh kiện (ước lượng, VND)
----------------------------------
BOM đầy đủ từng Ref (đế cầu chì 5×20 có nắp): **pcb/BOM.txt**

| Phạm vi | Thấp | Cao |
|---|---|-----|
| Khối nguồn (protect + buck + D12/C24 + Q5/D5, không relay) | ~165k | ~300k |
| Relay K1/K2 + driver + J5/J6 | ~55k | ~100k |
| Quang AFBR ×4 + decap | ~220k | ~480k |
| MCU socket + I/O + RS485 + domino J1–J8 + LED | ~75k | ~145k |
| **Tổng linh kiện trên PCB** (chưa ESP32 module, chưa PCB) | **~530k** | **~1.060k** |
| + ESP32-DevKitC | +90k | +185k |
| + PCB 2L 172×98 mm (lô nhỏ) | +25k | +120k |
| **Một máy lắp đủ (có DevKit + PCB)** | **~645k** | **~1.365k** |

Nguồn 24 V tủ: ~150k–400k. Giá AFBR và relay chiếm phần lớn biên độ trên.

11. Tệp trong kho Fiberboard
----------------------------
- KiCad: pcb/fiberboard-logic.kicad_pro
- BOM + giá: pcb/BOM.txt
- Sinh lại dự án: python pcb/scripts/generate_kicad_project.py
- Kiểm tra bố trí: python pcb/scripts/check_pcb_layout.py
- Ghi chú bo: pcb/DESIGN_NOTES.txt

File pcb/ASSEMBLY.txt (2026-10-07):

Lắp ráp theo vùng giắc cắm (DNP tùy chọn)
============================================

Mỗi nhóm OPT_* (một giắc) gồm **giắc cái** + linh kiện của giắc đó trong khung chữ nhật sát cọc. Hàng **cạnh dài trên**: J1, chân, NPN, quang. Hàng **cạnh dài dưới**, trái → phải: relay, van, J2 (24 V ra bàn phím), RS485 — giãn ra, cột đông linh kiện rộng hơn. Không còn nhóm công suất chung: cuộn, driver, lọc +5 V và MOSFET van nằm trong group của cọc tương ứng. Bảo vệ 24 V và buck vẫn là hai group nguồn dùng chung.

Bắt buộc (luôn lắp)
-------------------
| Nhóm | Nội dung |
|---|---|
| **CORE_PWR** | J1, J2. Một đèn mỗi giắc: D13 (R22 phía trong), D14 (R23 phía trong) |
| **PWR_24V_PROTECT** | F1, L2, C19, C15, RV1, D7, Q12, R17, C4, C14, đèn D27/R39 (debug +24 V, silk 24V), NT1, D11, C23, FB3 — tụ và trở sát nút chúng lọc |
| **PWR_BUCK** | C16, C17, U2, D8, L1, R36–R38, C2, C5, đèn D25/R34 (debug +5 V, silk 5V), FB2, C22, U3, đèn D6/R16 (debug 3,3 V, silk 3V3), C7, C3, C18, FB1, C21 |
| **CORE_MCU** | U1 (đế ESP32). R20/R21 và R40–R45 (trở nối tiếp GPIO) giữa hai hàng chân đế |

Tùy chọn theo giắc
------------------
| Nhóm | Giắc | Linh kiện phía trên / cùng cột |
|---|---|---|
| **OPT_J3_FOOT** | J3 | Đèn D15 sát giắc (R24 phía trong); U5, R7, R9. **R20** luôn lắp, giữa hai hàng chân đế |
| **OPT_J4_NPN** | J4 | Đèn D16 sát giắc (R25 phía trong); U6, R8, R10. **R21** luôn lắp, giữa hai hàng chân đế |
| **OPT_J5_RLY1** | J5 | Ngay trên cọc: K1, Q3, R11, D3, đèn D17 (R26 phía trong), lọc FB4, D12, C24, C25. Xóa cả group nếu không dùng relay 1 |
| **OPT_J6_RLY2** | J6 | Ngay trên cọc: K2, Q4, R12, D4, đèn D18 (R27 phía trong), lọc FB5, D26, C26, C27. Xóa cả group nếu không dùng relay 2 |
| **OPT_J7_SOL** | J7 | MOSFET Q5 ngay giữa cọc (silk **MOS**), D5 bên cạnh, rồi R13, R14, đèn D19 (R28 phía trong) |
| **OPT_J8_RS485** | J8 | Đèn D20 sát giắc (R29 phía trong); R15, R18, R19, D9, D10. U7 ở dải dưới ESP32 |
| **OPT_FIBER1** | F1T, F1R | Đèn D21, D22 sát mắt (R30, R31 phía trong); C12 |
| **OPT_FIBER2** | F2T, F2R | Đèn D23, D24 sát mắt (R32, R33 phía trong); C13 |
Ghi chú điện
------------
- Không lắp **OPT_J3/J4**: R20/R21 giữ IN_FOOT/IN_NPN ở mức thấp; firmware không đọc hoặc bỏ qua.
- Không lắp **OPT_J8**: không hàn MAX485; UART RS485 trên ESP32 không nối tải.
- Không dùng relay 1: xóa cả group **OPT_J5_RLY1**. Relay 2, buck và MCU không mất nguồn.
- Không dùng relay 2: xóa cả group **OPT_J6_RLY2**. Relay 1 vẫn chạy trên nhánh FB4 riêng.

Trên PCB: khung silk + nhóm KiCad trùng tên nhóm. Danh sách ref: `pcb/scripts/assembly_groups.py`.

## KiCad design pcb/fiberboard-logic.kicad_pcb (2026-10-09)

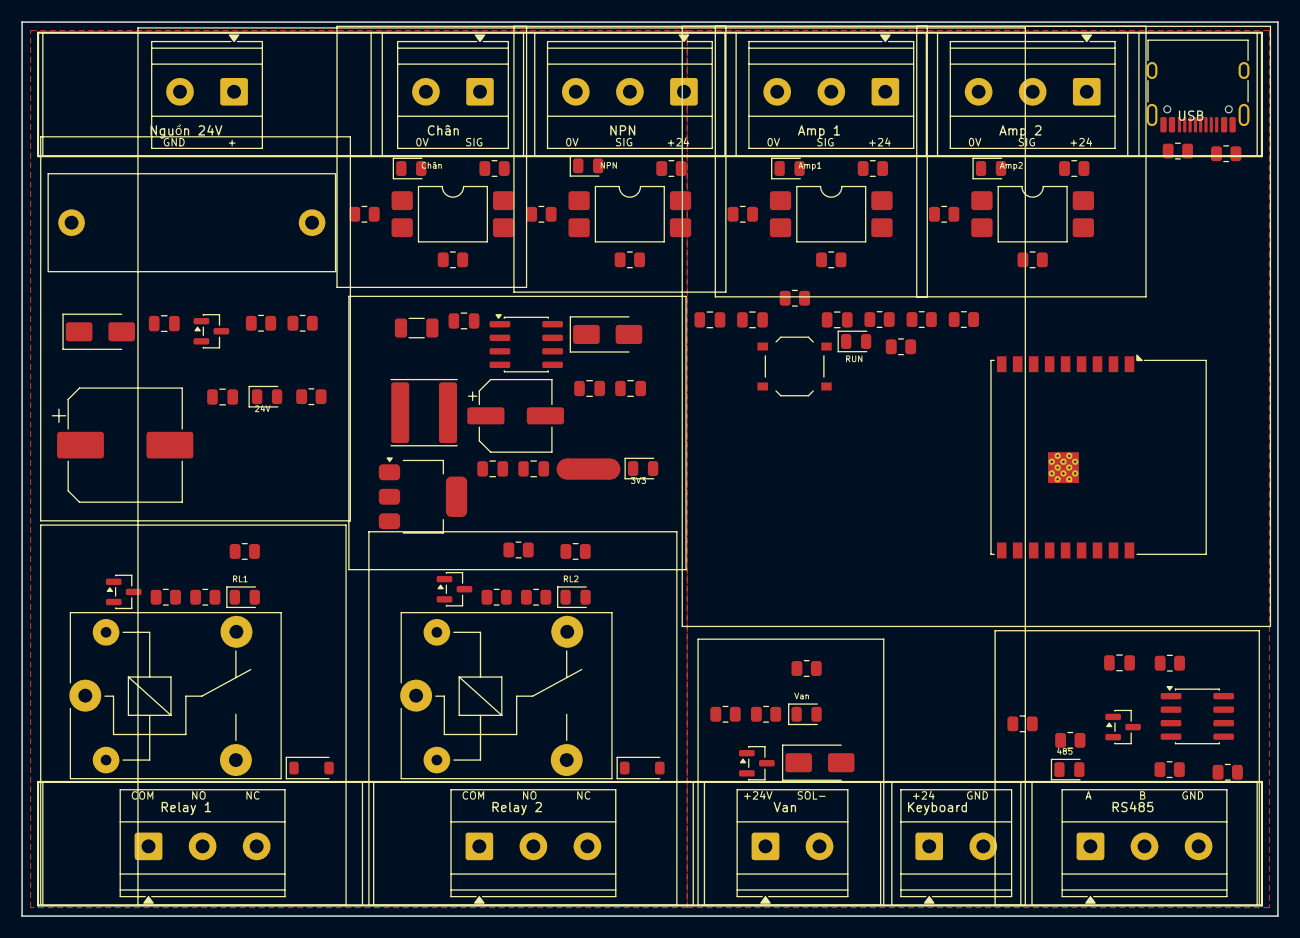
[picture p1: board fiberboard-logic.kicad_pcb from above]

Board: 2 copper layers, 118.0 x 84.0 mm, 97 parts (0 on the bottom side), 62 nets, no tracks yet.

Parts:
C2: 220uF 10V; CP_Elec_6.3x5.4
C3: 22uF; C_0805_2012Metric
C4: 470uF 35V; CP_Elec_10x10.5
C5, C9, C11, C18: 100nF; C_0805_2012Metric
C7, C8: 10uF; C_0805_2012Metric
C10: 1uF; C_0805_2012Metric
C14, C15, C17: 100nF 50V; C_0805_2012Metric
C16: 10uF 50V; C_1206_3216Metric
D3, D4: 1N4148W; D_SOD-123
D5, D8: SS34; D_SMA
D6: 3V3; LED_0805_2012Metric
D7: SMAJ26A; D_SMA
D9: PSM712; SOT-23
D15: FOOT; LED_0805_2012Metric
D16: NPN; LED_0805_2012Metric
D17: RLY1; LED_0805_2012Metric
D18: RLY2; LED_0805_2012Metric
D19: VAN; LED_0805_2012Metric
D20: 485; LED_0805_2012Metric
D27: 24V; LED_0805_2012Metric
D30: RUN; LED_0805_2012Metric
D31: AMP1; LED_0805_2012Metric
D32: AMP2; LED_0805_2012Metric
F1: 5x20 su 4A; Fuseholder_5x20mm_Covered
J1: VIN; Terminal_2EDG5.08-1x02_P5.08mm_Horizontal
J2: KB24; Terminal_2EDG5.08-1x02_P5.08mm_Horizontal
J3: FOOT; Terminal_2EDG5.08-1x02_P5.08mm_Horizontal
J4: NPN; Terminal_2EDG5.08-1x03_P5.08mm_Horizontal
J5: RLY1; Terminal_2EDG5.08-1x03_P5.08mm_Horizontal
J6: RLY2; Terminal_2EDG5.08-1x03_P5.08mm_Horizontal
J7: SOL; Terminal_2EDG5.08-1x02_P5.08mm_Horizontal
J8: RS485; Terminal_2EDG5.08-1x03_P5.08mm_Horizontal
J9: AMP1; Terminal_2EDG5.08-1x03_P5.08mm_Horizontal
J10: AMP2; Terminal_2EDG5.08-1x03_P5.08mm_Horizontal
J11: USB-C; USB_C_Receptacle_HRO_TYPE-C-31-M-12
K1, K2: HF3FF-024-1ZS; Relay_SPDT_SANYOU_SRD_Series_Form_C
L1: 47uH 6045; L_Sunlord_SWPA6045S
NT1: GND_STAR; NetTie-2_SMD_Pad2.0mm
Q3, Q4: MMBT3904; SOT-23
Q5: AO3400A; SOT-23
Q12: AO3401A; SOT-23
R7, R8, R9, R10, R14, R26, R27, R28, R39, R47, R48, R49, R52, R53, R54, R55, R57, R58, R60, R61, R63: 10k; R_0805_2012Metric
R11, R12, R16, R24, R25, R29, R56, R59, R62: 1k; R_0805_2012Metric
R13, R18, R19: 10R; R_0805_2012Metric
R15: 120R; R_0805_2012Metric
R17: 27k; R_0805_2012Metric
R50, R51: 5.1k; R_0805_2012Metric
SW1: BOOT; SW_Push_1P1T_XKB_TS-1187A
U1: ESP32-C3-WROOM-02
U2: XL1509-5.0; SOIC-8_3.9x4.9mm_P1.27mm
U3: AMS1117-3.3; SOT-223-3_TabPin2
U5, U6, U9, U10: LTV-817S; SMDIP-4_W9.53mm
U7: SP3485EN; SOIC-8_3.9x4.9mm_P1.27mm

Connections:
+3V3: C3.1, C8.1, C9.1, C11.1, C18.1, R9.1, R10.1, R16.1, R24.1, R25.1, R52.1, R53.1, R54.1, R55.1, R56.1, R58.1, R59.1, R61.1, R62.1, U1.1, U3.2, U7.8
+5V: C2.1, C5.1, C7.1, L1.2, U2.3, U3.3
+24V: C4.1, C14.1, C16.1, C17.1, D3.1, D4.1, D5.1, J2.1, J4.1, J7.1, J9.1, J10.1, K1.5, K2.5, Q12.2, R7.1, R8.1, R26.1, R27.1, R28.1, R39.1, R57.1, R60.1, R63.1, U2.1
AMP1_AN: R57.2, U9.1
AMP1_SIG: J9.2, U9.2
AMP2_AN: R60.2, U10.1
AMP2_SIG: J10.2, U10.2
BUCK_SW: D8.1, L1.1, U2.2
ESP_BOOT: R55.2, SW1.1, U1.8
ESP_EN: C10.1, R52.2, U1.2
ESP_IO2: R53.2, U1.16
FET_G: Q12.1, R17.1, R63.2
FOOT_AN: R7.2, U5.1
FOOT_SIG: J3.1, U5.2
GND: C3.2, C7.2, C8.2, C9.2, C10.2, C11.2, C18.2, D6.1, D9.3, D20.1, J8.3, J11.A1, J11.A12, J11.B1, J11.B12, J11.SH, NT1.2, R49.2, R50.2, R51.2, SW1.2, U1.9, U1.19, U3.1, U5.3, U6.3, U7.5, U9.3, U10.3
GND_PWR: C2.2, C4.2, C5.2, C14.2, C15.2, C16.2, C17.2, D7.2, D8.2, D27.1, J1.2, J2.2, J3.2, J4.3, J9.3, J10.3, NT1.1, Q3.2, Q4.2, Q5.2, R14.2, R17.2, R47.2, R48.2, U2.4, U2.5, U2.6, U2.7, U2.8
IN_AMP1: D31.1, R58.2, U1.5, U9.4
IN_AMP2: D32.1, R61.2, U1.6, U10.4
IN_FOOT: D15.1, R9.2, U1.3, U5.4
IN_NPN: D16.1, R10.2, U1.4, U6.4
J3_AN: D15.2, R24.2
J4_AN: D16.2, R25.2
J5_AN: D17.2, R26.2
J6_AN: D18.2, R27.2
J7_AN: D19.2, R28.2
J8_AN: D20.2, R29.2
J9_AN: D31.2, R59.2
J10_AN: D32.2, R62.2
LED_RUN: D30.1, R54.2, U1.7
MOS_G: Q5.1, R13.2, R14.1
NPN_AN: R8.2, U6.1
NPN_SIG: J4.2, U6.2
OUT_MOS: R13.1, U1.10
OUT_RLY1: R11.1, U1.18
OUT_RLY2: R12.1, U1.17
P3V3_AN: D6.2, R16.2
P24_AN: D27.2, R39.2
RLY1_B: Q3.1, R11.2, R47.1
RLY1_COIL: D3.2, D17.1, K1.2, Q3.3
RLY1_COM: J5.1, K1.1
RLY1_NC: J5.3, K1.4
RLY1_NO: J5.2, K1.3
RLY2_B: Q4.1, R12.2, R48.1
RLY2_COIL: D4.2, D18.1, K2.2, Q4.3
RLY2_COM: J6.1, K2.1
RLY2_NC: J6.3, K2.4
RLY2_NO: J6.2, K2.3
RS485_A: R18.1, U7.6
RS485_A_BUS: D9.1, J8.1, R15.1, R18.2
RS485_B: R19.1, U7.7
RS485_B_BUS: D9.2, J8.2, R15.2, R19.2
RS485_DE: R29.1, R49.1, U1.15, U7.2, U7.3
RS485_RX: U1.11, U7.1
RS485_TX: U1.12, U7.4
RUN_AN: D30.2, R56.2
SOL_LO: D5.2, D19.1, J7.2, Q5.3
USB_CC1: J11.A5, R50.1
USB_CC2: J11.B5, R51.1
USB_DN: J11.A7, J11.B7, U1.13
USB_DP: J11.A6, J11.B6, U1.14
VIN_FUSE: C15.1, D7.1, F1.2, Q12.3
VIN_RAW: F1.1, J1.1

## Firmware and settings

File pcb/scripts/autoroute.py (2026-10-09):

"""Grid autorouter (classic maze / A* with rip-up-and-retry) for fiberboard-logic.kicad_pcb.

Usage:  python autoroute.py [--pcb FILE] [--png preview.png] [--passes N] [--dry]

Algorithm
  * 0.1 mm Manhattan grid, 2 copper layers (F.Cu prefers horizontal, B.Cu vertical).
  * Every pad first gets a straight *stub* leaving the pad (hand-assembly rule: the
    track runs straight out of the pin for >= STUB_LEN mm before it may turn).
  * Nets are connected pad-by-pad (Prim order) with A* (cost = length + wrong-way +
    bend + via), clearance/width-aware obstacle masks, T-joins on the net's own copper.
  * Failed nets are moved to the front and everything is re-routed (up to --passes).
  * GND / GND_PWR are left to the copper pours; SMD ground pads get stub + stitch via.
  * Result is written back as (segment ...) / (via ...) items; earlier ones are replaced.
"""

from __future__ import annotations

import argparse
import heapq
import math
import re
import sys
import time
import uuid
from dataclasses import dataclass, field
from pathlib import Path

import numpy as np

sys.path.insert(0, str(Path(__file__).resolve().parent))
from pcb_parse import Pad, load_board  # noqa: E402

try:  # compiled search core; pure-Python astar() below is the fallback
    from maze_nb import Maze  # noqa: E402
except ImportError:  # pragma: no cover
    Maze = None

G = 0.1  # grid pitch (mm)
CLR = 0.20  # copper clearance (kicad_pro min_clearance)
CLR_POWER = 0.30
SAFE = 0.03  # extra clearance margin for off-grid stub geometry
EDGE_CLR = 0.45  # copper to board edge
STUB_LENS = (0.6, 0.45, 0.3)  # straight run beyond pad edge, preferred first
STUB_LEN_GND = (0.7, 0.9, 1.2, 1.6, 0.5)
VIA_SIGNAL = (0.6, 0.3)
VIA_POWER = (0.8, 0.4)
GND_NETS = ("GND", "GND_PWR")
KEEPOUT_NET = -999_999
GND_STITCH = False  # True: old behaviour (pads -> stub + via into the pour, no tracks)

# cost model (integers, 10 == one grid step)
C_STEP = 10
C_WRONG = 5
C_BEND = 25
C_VIA = 140
MAX_EXPAND = 500_000  # pure-Python search
MAX_EXPAND_NB = 3_000_000  # numba search
H_WEIGHT = 2.2  # weighted A*: trades optimality for speed

POWER_HI = {
    "+24V", "VIN_RAW", "VIN_FUSE", "SOL_LO",
    "RLY1_COM", "RLY1_NO", "RLY1_NC", "RLY2_COM", "RLY2_NO", "RLY2_NC",
}
POWER_MID = {"+5V", "+3V3", "BUCK_SW"}
# USB-C 16P (bước 0,5 mm): netclass "USB" trong kicad_pro
USB_RULE = {"width": 0.15, "clearance": 0.13, "via": (0.45, 0.2)}


def width_ladder(net: str) -> tuple[float, ...]:
    if net.startswith("USB_"):  # USB-C 0.5 mm pitch pads
        return (USB_RULE["width"],)
    if net in POWER_HI:
        return (0.8, 0.6, 0.4, 0.25)
    if net in POWER_MID or net in GND_NETS:
        return (0.5, 0.4, 0.25)
    return (0.25,)


def via_for(w: float) -> tuple[float, float]:
    return VIA_POWER if w >= 0.5 else VIA_SIGNAL


def clr_for(net: str) -> float:
    if net.startswith("USB_"):
        return USB_RULE["clearance"]
    return CLR_POWER if net in POWER_HI else CLR


# ----------------------------------------------------------------------------- board model
def _crt_overlap(a, c, tol: float = 0.02) -> bool:
    if not a or not c:
        return False
    return min(a[2], c[2]) - max(a[0], c[0]) > tol and min(a[3], c[3]) - max(a[1], c[1]) > tol


@dataclass
class Rect:
    x0: float
    y0: float
    x1: float
    y1: float
    net: int
    kind: str  # pad / smdpad / track / via


@dataclass
class Stub:
    pad: Pad
    layers: tuple[int, ...]  # layers on which the pad can start a route
    ex: float  # exact stub end
    ey: float
    dx: int
    dy: int
    nx: int  # grid node continuing the stub
    ny: int
    direction: int
    length: float
    big: bool = False


class Board:
    def __init__(self, path: str):
        self.text, self.fps, edge = load_board(path)
        self.x0, self.y0, self.x1, self.y1 = edge
        self.W = int(round((self.x1 - self.x0) / G)) + 1
        self.H = int(round((self.y1 - self.y0) / G)) + 1
        self.HW = self.H * self.W
        self.net_id: dict[str, int] = {}
        self.net_name: dict[int, str] = {}
        self.rects: list[list[Rect]] = [[], []]
        self._cache: list[tuple | None] = [None, None]
        self.pads_by_net: dict[str, list[Pad]] = {}
        self.pad_centroid: dict[int, tuple[float, float]] = {}
        self.pour: dict[str, list[list[tuple[float, float]]]] = {}
        self.moved: dict[str, tuple[float, float]] = {}
        self.orig_pos = {f.ref: (f.x, f.y) for f in self.fps}
        # courtyard overlaps already present in the placement (e.g. parts in the ESP32 pocket) stay allowed
        self.orig_overlap = {(a.ref, c.ref) for a in self.fps for c in self.fps
                             if a is not c and _crt_overlap(a.crtyd, c.crtyd)}
        self._load_pads()
        self._load_pours()
        self.static_counts = [len(self.rects[0]), len(self.rects[1])]

    # -- component nudging
    MOVABLE = ("R", "C", "D", "FB", "L", "LED", "Q")
    NUDGE_MAX = 3.0

    def movable(self, fp) -> bool:
        pre = re.match(r"[A-Za-z]+", fp.ref)
        return bool(pre) and pre.group(0) in self.MOVABLE and len(fp.pads) <= 3 and all(p.smd for p in fp.pads)

    def rebuild_static(self) -> None:
        tracks = [self.rects[L][self.static_counts[L]:] for L in (0, 1)]
        self.rects = [[], []]
        self._cache = [None, None]
        self.pads_by_net = {}
        self._load_pads()
        self.static_counts = [len(self.rects[0]), len(self.rects[1])]
        for L in (0, 1):
            self.rects[L].extend(tracks[L])

    def move_fp(self, fp, dx: float, dy: float) -> None:
        fp.x += dx
        fp.y += dy
        if fp.crtyd:
            x0, y0, x1, y1 = fp.crtyd
            fp.crtyd = (x0 + dx, y0 + dy, x1 + dx, y1 + dy)
        for p in fp.pads:
            p.x += dx
            p.y += dy
        self.moved[fp.ref] = (fp.x - self.orig_pos[fp.ref][0], fp.y - self.orig_pos[fp.ref][1])
        self.rebuild_static()

    def fp_gap_ok(self, fp, gap: float = 0.35) -> bool:
        """Moved footprint keeps `gap` between its pads and every other footprint's pads, and the board edge."""
        for o in self.fps:
            if o is not fp and (fp.ref, o.ref) not in self.orig_overlap and _crt_overlap(fp.crtyd, o.crtyd):
                return False
        for p in fp.pads:
            if (p.x - p.w / 2 < self.x0 + 1.0 or p.x + p.w / 2 > self.x1 - 1.0
                    or p.y - p.h / 2 < self.y0 + 1.0 or p.y + p.h / 2 > self.y1 - 1.0):
                return False
            for o in self.fps:
                if o is fp:
                    continue
                for q in o.pads:
                    if abs(q.x - p.x) > 6 or abs(q.y - p.y) > 6:
                        continue
                    ddx = max(q.x - q.w / 2 - (p.x + p.w / 2), p.x - p.w / 2 - (q.x + q.w / 2), 0.0)
                    ddy = max(q.y - q.h / 2 - (p.y + p.h / 2), p.y - p.h / 2 - (q.y + q.h / 2), 0.0)
                    if math.hypot(ddx, ddy) < gap:
                        return False
        return True

    def apply_moves(self, text: str) -> str:
        for ref, (dx, dy) in self.moved.items():
            if abs(dx) < 1e-9 and abs(dy) < 1e-9:
                continue
            k = text.find(f'(property "Reference" "{ref}"')
            f0 = text.rfind("	(footprint ", 0, k)
            m = re.compile(r"\(at ([-\d.]+) ([-\d.]+)( [-\d.]+)?\)").search(text, f0)
            nx, ny = float(m.group(1)) + dx, float(m.group(2)) + dy
            text = text[:m.start()] + f"(at {nx:.4f} {ny:.4f}{m.group(3) or ''})" + text[m.end():]
        return text

    # -- nets
    def nid(self, name: str) -> int:
        if name not in self.net_id:
            i = len(self.net_id) + 1
            self.net_id[name] = i
            self.net_name[i] = name
        return self.net_id[name]

    def _load_pads(self) -> None:
        anon = -1
        for fp in self.fps:
            cx = sum(p.x for p in fp.pads) / max(1, len(fp.pads))
            cy = sum(p.y for p in fp.pads) / max(1, len(fp.pads))
            fp.pads = [p for p in fp.pads if any(l in ("F.Cu", "B.Cu", "*.Cu") for l in p.layers)]  # drop paste-only apertures
            for ko in fp.keepouts:  # e.g. ESP32 antenna: no copper of any net
                for L in (0, 1):
                    self.add_rect(L, *ko, KEEPOUT_NET, "keepout")
            for p in fp.pads:
                self.pad_centroid[id(p)] = (cx, cy)
                if p.net:
                    n = self.nid(p.net)
                    self.pads_by_net.setdefault(p.net, []).append(p)
                else:
                    n = anon
                    anon -= 1
                lays = self.pad_layers(p)
                for L in lays:
                    self.add_rect(L, p.x - p.w / 2, p.y - p.h / 2, p.x + p.w / 2, p.y + p.h / 2, n,
                                  "smdpad" if p.smd else "pad")

    @staticmethod
    def pad_layers(p: Pad) -> tuple[int, ...]:
        if any(l in ("*.Cu",) for l in p.layers) or (not p.smd):
            return (0, 1)
        if "B.Cu" in p.layers and "F.Cu" not in p.layers:
            return (1,)
        return (0,)

    def _load_pours(self) -> None:
        for m in re.finditer(r'\(zone\s+\(net \d+\)\s+\(net_name "([^"]+)"\)\s+\(layer "([^"]+)"\)(.*?)\(polygon\s+\(pts(.*?)\)\s*\)',
                             self.text, re.S):
            name, layer, _, pts = m.groups()
            poly = [(float(a), float(b)) for a, b in re.findall(r"\(xy ([-\d.]+) ([-\d.]+)\)", pts)]
            self.pour.setdefault(name, []).append(poly)

    def in_pour(self, net: str, x: float, y: float, margin: float) -> bool:
        for poly in self.pour.get(net, []):
            xs = [p[0] for p in poly]
            ys = [p[1] for p in poly]
            if min(xs) + margin <= x <= max(xs) - margin and min(ys) + margin <= y <= max(ys) - margin:
                return True  # pours here are axis-aligned rectangles
        return False

    # -- rect store
    def add_rect(self, layer, x0, y0, x1, y1, net, kind) -> None:
        self.rects[layer].append(Rect(x0, y0, x1, y1, net, kind))
        self._cache[layer] = None

    def arrays(self, layer: int):
        if self._cache[layer] is None:
            r = self.rects[layer]
            a = np.array([[q.x0, q.y0, q.x1, q.y1, q.net] for q in r], dtype=float).reshape(-1, 5)
            self._cache[layer] = a
        return self._cache[layer]

    def exact_clear(self, layer, rx0, ry0, rx1, ry1, net, clr) -> bool:
        a = self.arrays(layer)
        if not len(a):
            return True
        m = a[:, 4] != net
        dx = np.maximum(np.maximum(a[:, 0] - rx1, rx0 - a[:, 2]), 0.0)
        dy = np.maximum(np.maximum(a[:, 1] - ry1, ry0 - a[:, 3]), 0.0)
        d = np.hypot(dx, dy)
        if np.any(d[m] < clr - 1e-9):
            return False
        # board edge
        return (rx0 >= self.x0 + EDGE_CLR - 1e-9 and ry0 >= self.y0 + EDGE_CLR - 1e-9
                and rx1 <= self.x1 - EDGE_CLR + 1e-9 and ry1 <= self.y1 - EDGE_CLR + 1e-9)

    # -- grid masks
    def build_masks(self, net: int, netname: str, w: float, vd: float):
        """Return (track_blocked[2], via_blocked) as uint8 H*W arrays."""
        c = clr_for(netname) + SAFE
        H, W = self.H, self.W
        mt = [np.zeros((H, W), np.uint8), np.zeros((H, W), np.uint8)]
        mv = [np.zeros((H, W), np.uint8), np.zeros((H, W), np.uint8)]
        for L in (0, 1):
            for r in self.rects[L]:
                own = r.net == net
                if own and r.kind != "smdpad":
                    continue
                if own:  # never drop vias onto own SMD pads (hand soldering)
                    dv = vd / 2 + 0.12
                    self._paint(mv[L], r, dv)
                    continue
                cc = max(c, clr_for(self.net_name.get(r.net, "")) + SAFE)
                self._paint(mt[L], r, w / 2 + cc)
                self._paint(mv[L], r, vd / 2 + cc)
            for m, half in ((mt[L], w / 2), (mv[L], vd / 2)):
                e = EDGE_CLR + half
                n = int(math.ceil(e / G)) + 1
                m[:n, :] = 1
                m[-n:, :] = 1
                m[:, :n] = 1
                m[:, -n:] = 1
        via_bad = (mv[0] | mv[1]).astype(np.uint8)
        return [m.ravel().tobytes() for m in mt], via_bad.ravel().tobytes()

    def _paint(self, m: np.ndarray, r: Rect, d: float) -> None:
        i0 = int(math.floor((r.x0 - self.x0 - d) / G + 1e-9)) + 1
        i1 = int(math.ceil((r.x1 - self.x0 + d) / G - 1e-9)) - 1
        j0 = int(math.floor((r.y0 - self.y0 - d) / G + 1e-9)) + 1
        j1 = int(math.ceil((r.y1 - self.y0 + d) / G - 1e-9)) - 1
        if i1 < 0 or j1 < 0 or i0 >= self.W or j0 >= self.H:
            return
        m[max(j0, 0): j1 + 1, max(i0, 0): i1 + 1] = 1

    # -- coordinates
    def cell_xy(self, i: int) -> tuple[float, float]:
        return self.x0 + (i % self.W) * G, self.y0 + (i // self.W) * G

    def xy_cell(self, x: float, y: float) -> int:
        return int(round((y - self.y0) / G)) * self.W + int(round((x - self.x0) / G))


# ----------------------------------------------------------------------------- stubs
DIRS = [(1, 0), (0, 1), (-1, 0), (0, -1)]  # E S W N  (y grows downward)


def _dir_index(dx: int, dy: int) -> int:
    return DIRS.index((dx, dy))


def stub_candidates(b: Board, p: Pad, mt: list[bytes] | None) -> list[tuple[int, int]]:
    cx, cy = b.pad_centroid[id(p)]
    vx, vy = p.x - cx, p.y - cy
    sx = (1 if vx >= 0 else -1)
    sy = (1 if vy >= 0 else -1)
    long_h, long_v = p.w > p.h * 2.0, p.h > p.w * 2.0
    if long_h:
        order = [(sx, 0), (0, sy), (0, -sy), (-sx, 0)]
    elif long_v:
        order = [(0, sy), (sx, 0), (-sx, 0), (0, -sy)]
    elif abs(vx) >= abs(vy):
        order = [(sx, 0), (0, sy), (0, -sy), (-sx, 0)]
    else:
        order = [(0, sy), (sx, 0), (-sx, 0), (0, -sy)]
    if not p.smd and not (long_h or long_v):
        # through-hole: prefer the direction with the longest free run (outward on ties)
        def run(d):
            n = 0
            x, y = p.x, p.y
            half = (p.w if d[0] else p.h) / 2
            for k in range(1, 40):
                xx, yy = x + d[0] * (half + k * G), y + d[1] * (half + k * G)
                if not b.exact_clear(0, xx - 0.125, yy - 0.125, xx + 0.125, yy + 0.125, b.nid(p.net) if p.net else -999, CLR + SAFE):
                    break
                n = k
            return min(n * G, 1.0)
        order.sort(key=lambda d: -run(d))
    return order


def pick_stub(b: Board, p: Pad, lens=STUB_LENS, w: float = 0.25, mt=None) -> Stub | None:
    net = b.nid(p.net)
    c = clr_for(p.net) + SAFE
    lays = b.pad_layers(p)
    for d in stub_candidates(b, p, None):
        half = (p.w if d[0] else p.h) / 2
        for ln in lens:
            ex = p.x + d[0] * (half + ln)
            ey = p.y + d[1] * (half + ln)
            # snap along-axis coordinate to the grid so the route continues on-grid
            # (round away from the pad so the straight run is never shorter than asked)
            if d[0]:
                k = (ex - b.x0) / G
                ex = b.x0 + (math.floor(k + 1e-9) if d[0] < 0 else math.ceil(k - 1e-9)) * G
            else:
                k = (ey - b.y0) / G
                ey = b.y0 + (math.floor(k + 1e-9) if d[1] < 0 else math.ceil(k - 1e-9)) * G
            if (ex - p.x) * d[0] + (ey - p.y) * d[1] < half + min(lens) - 1e-6:
                continue
            nx = int(round((ex - b.x0) / G))
            ny = int(round((ey - b.y0) / G))
            gx, gy = b.x0 + nx * G, b.y0 + ny * G
            ok_layers = []
            for L in lays:
                # stub rect (pad centre -> end) + jog to grid node
                x0, x1 = sorted((p.x, ex))
                y0, y1 = sorted((p.y, ey))
                hw = w / 2
                if mt is not None and mt[L][ny * b.W + nx]:
                    continue
                if b.exact_clear(L, x0 - hw, y0 - hw, x1 + hw, y1 + hw, net, c) and \
                   b.exact_clear(L, min(ex, gx) - hw, min(ey, gy) - hw, max(ex, gx) + hw, max(ey, gy) + hw, net, c):
                    ok_layers.append(L)
            if ok_layers:
                return Stub(p, tuple(ok_layers), ex, ey, d[0], d[1], nx, ny, _dir_index(*d), ln)
    return None


# ----------------------------------------------------------------------------- search
def astar(b: Board, sources, targets: set[int], samples, mt, via_bad):
    """sources: list of (layer, cell, dir). targets: set of layer*HW+cell. Returns list of (layer, cell) or None."""
    W, HW = b.W, b.HW
    OFF = (1, W, -1, -W)
    heap: list = []
    g: dict[int, int] = {}
    parent: dict[int, int] = {}
    sx = [(s % W, s // W) for s in samples]

    def h(i: int) -> int:
        x, y = i % W, i // W
        return int(H_WEIGHT * C_STEP * min(abs(x - a) + abs(y - c) for a, c in sx))

    for L, cell, d in sources:
        s = (L * HW + cell) * 4 + d
        g[s] = 0
        heapq.heappush(heap, (h(cell), 0, s))
    expanded = 0
    while heap:
        f, gc, s = heapq.heappop(heap)
        if gc > g.get(s, 1 << 60):
            continue
        key = s >> 2
        d = s & 3
        L, i = divmod(key, HW)
        if key in targets:
            path = []
            cur = s
            while True:
                path.append(cur >> 2)
                if cur not in parent:
                    break
                cur = parent[cur]
            path.reverse()
            return [(k // HW, k % HW) for k in path]
        expanded += 1
        if expanded > MAX_EXPAND:
            return None
        mL = mt[L]
        pref_h = (L == 0)
        for nd in range(4):
            if nd == (d + 2) & 3:
                continue
            ni = i + OFF[nd]
            if mL[ni]:
                continue
            horiz = nd in (0, 2)
            cost = C_STEP + (0 if horiz == pref_h else C_WRONG) + (C_BEND if nd != d else 0)
            ng = gc + cost
            ns = (L * HW + ni) * 4 + nd
            if ng < g.get(ns, 1 << 60):
                g[ns] = ng
                parent[ns] = s
                heapq.heappush(heap, (ng + h(ni), ng, ns))
        if not via_bad[i]:
            L2 = 1 - L
            if not mt[L2][i]:
                ns = (L2 * HW + i) * 4 + d
                ng = gc + C_VIA
                if ng < g.get(ns, 1 << 60):
                    g[ns] = ng
                    parent[ns] = s
                    heapq.heappush(heap, (ng + h(i), ng, ns))
    return None


# ----------------------------------------------------------------------------- router
@dataclass
class Result:
    segs: list[tuple[float, float, float, float, int, float, str]] = field(default_factory=list)
    vias: list[tuple[float, float, float, float, str]] = field(default_factory=list)
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

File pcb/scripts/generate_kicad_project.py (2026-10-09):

#!/usr/bin/env python3
"""Generate KiCad 10 project: Fiberboard All-In-One Logic (no stepper)."""

from __future__ import annotations

import json
import re
import sys
import uuid
from pathlib import Path

ROOT = Path(__file__).resolve().parents[1]
sys.path.insert(0, str(Path(__file__).resolve().parent))
from build_connected import (  # noqa: E402
    emit_connected_schematic,
    inject_nets_into_footprint,
    pad_net_table,
)
from connectivity import USB_C_PINS, build_logic_design  # noqa: E402
from assembly_groups import assembly_group  # noqa: E402
from pcb_layout import (  # noqa: E402
    BOARD_H,
    BOARD_W,
    DIN_RAIL_INSET,
    ZONES,
    build_layout,
    ground_pour_polygons,
    group_sexpr,
    passive_mark_silk,
    postprocess_footprint,
    zone_group,
)
from symbols_pcb_matched import (  # noqa: E402
    all_symbols_for_lib,
    all_symbols_for_schematic_embed,
)

_KICAD_CANDIDATES = (
    Path(r"C:\Users\duchan.nguyen\AppData\Local\Programs\KiCad\10.0\share\kicad"),
    Path.home() / "AppData/Local/Programs/KiCad/10.0/share/kicad",
)
KICAD = next((p for p in _KICAD_CANDIDATES if p.is_dir()), _KICAD_CANDIDATES[0])
SYM_DIR = KICAD / "symbols"
FP_DIR = KICAD / "footprints"
PROJECT = "fiberboard-logic"
SHEET_UUID = str(uuid.uuid4())
# Schematic mirrors PCB XY (mm): sch = OFFSET + pcb * SCALE
SCH_SCALE = 2.0
SCH_OX = 40.0
SCH_OY = 35.0


def uid() -> str:
    return str(uuid.uuid4())


def _extract_raw_symbol(text: str, name: str) -> str:
    needle = f'(symbol "{name}"'
    start = text.find(needle)
    if start < 0:
        raise KeyError(name)
    i = start
    depth = 0
    while i < len(text):
        ch = text[i]
        if ch == "(":
            depth += 1
        elif ch == ")":
            depth -= 1
            if depth == 0:
                return text[start : i + 1]
        i += 1
    raise RuntimeError(f"Unbalanced symbol {name}")


def _resolve_symbol_root(text: str, name: str, _seen: set[str] | None = None) -> tuple[str, str]:
    """Follow extends until a symbol that contains pins. Returns (root_name, root_block)."""
    seen = _seen or set()
    if name in seen:
        raise RuntimeError(f"extends cycle at {name}")
    seen.add(name)
    block = _extract_raw_symbol(text, name)
    if "(pin " in block:
        return name, block
    m = re.search(r'\(extends "([^"]+)"\)', block)
    if m:
        return _resolve_symbol_root(text, m.group(1), seen)
    raise KeyError(f"No pins found in symbol chain for {name}")


def extract_symbol(lib_path: Path, name: str) -> list[str]:
    """Return a self-contained lib_symbol block (extends fully flattened).

    KiCad sch upgrade can drop `(extends ...)` without copying parent pins,
    leaving pinless aliases (AO3400A, LM358, MAX485E, ...). Flattening here
    makes connectivity reliable.
    """
    text = lib_path.read_text(encoding="utf-8")
    lib = lib_path.stem
    derived = _extract_raw_symbol(text, name)

    try:
        root_name, root_block = _resolve_symbol_root(text, name)
    except KeyError:
        # XL1509-5.0 may be a thin alias; fall back to any XL1509-* with pins
        if name.startswith("XL1509"):
            for cand in re.findall(r'\(symbol "(XL1509[^"]+)"', text):
                if "(pin " in _extract_raw_symbol(text, cand):
                    root_name, root_block = cand, _extract_raw_symbol(text, cand)
                    break
            else:
                raise
        else:
            raise

    flat = root_block.replace(f'(symbol "{root_name}"', f'(symbol "{lib}:{name}"', 1)
    flat = re.sub(rf'\(symbol "{re.escape(root_name)}_', f'(symbol "{name}_', flat)
    # Prefer derived Value / footprint / datasheet when present on the alias
    for prop in ("Value", "Footprint", "Datasheet", "Description", "ki_keywords", "ki_fp_filters"):
        pm = re.search(
            rf'\(property "{prop}" "([^"]*)"([\s\S]*?\n\t\t\)\n)',
            derived,
        )
        if not pm:
            continue
        new_prop = f'(property "{prop}" "{pm.group(1)}"{pm.group(2)}'
        flat, n = re.subn(
            rf'\(property "{prop}" "[^"]*"([\s\S]*?\n\t\t\)\n)',
            new_prop,
            flat,
            count=1,
        )
        if n == 0:
            flat = flat.replace(
                f'(symbol "{lib}:{name}"\n',
                f'(symbol "{lib}:{name}"\n\t\t{new_prop}',
                1,
            )
    return [flat]


def extract_footprint(pretty: str, mod: str) -> str:
    path = FP_DIR / f"{pretty}.pretty" / f"{mod}.kicad_mod"
    return path.read_text(encoding="utf-8")


def place_symbol(
    lib_id: str,
    ref: str,
    value: str,
    x: float,
    y: float,
    footprint: str = "",
    rotation: int = 0,
    unit: int = 1,
    dnp: bool = False,
    in_bom: bool = True,
    pin_count: int = 8,
    pin_numbers: list[str] | None = None,
    show_value: bool = False,
    lcsc: str = "",
) -> str:
    if pin_numbers is None:
        # Most parts 1..N; USB-C uses A/B row names
        if "USB_C_Receptacle" in lib_id:
            pin_numbers = list(USB_C_PINS)
        else:
            pin_numbers = [str(i) for i in range(1, pin_count + 1)]
    pins = [f'\t\t(pin "{n}"\n\t\t\t(uuid "{uid()}")\n\t\t)' for n in pin_numbers]
    pin_block = "\n".join(pins)
    if show_value:
        value_at = f"{x + 5.08} {y}"
        value_size = "1.016"
        value_hide = ""
    else:
        value_at = f"{x} {y + 2.54}"
        value_size = "1.27"
        value_hide = "\n\t\t\t\t(hide yes)"
    return f'''\t(symbol
\t\t(lib_id "{lib_id}")
\t\t(at {x} {y} {rotation})
\t\t(unit {unit})
\t\t(exclude_from_sim no)
\t\t(in_bom {"yes" if in_bom else "no"})
\t\t(on_board yes)
\t\t(dnp {"yes" if dnp else "no"})
\t\t(uuid "{uid()}")
\t\t(property "Reference" "{ref}"
\t\t\t(at {x} {y - 2.54} 0)
\t\t\t(effects
\t\t\t\t(font
\t\t\t\t\t(size 1.27 1.27)
\t\t\t\t)
\t\t\t\t(hide yes)
\t\t\t)
\t\t)
\t\t(property "Value" "{value}"
\t\t\t(at {value_at} 0)
\t\t\t(effects
\t\t\t\t(font
\t\t\t\t\t(size {value_size} {value_size})
\t\t\t\t){value_hide}
\t\t\t)
\t\t)
\t\t(property "Footprint" "{footprint}"
\t\t\t(at {x} {y} 0)
\t\t\t(effects
\t\t\t\t(font
\t\t\t\t\t(size 1.27 1.27)
\t\t\t\t)
\t\t\t\t(hide yes)
\t\t\t)
\t\t)
\t\t(property "Datasheet" ""
\t\t\t(at {x} {y} 0)
\t\t\t(effects
\t\t\t\t(font
\t\t\t\t\t(size 1.27 1.27)
\t\t\t\t)
\t\t\t\t(hide yes)
\t\t\t)
\t\t)
\t\t(property "LCSC" "{lcsc}"
\t\t\t(at {x} {y} 0)
\t\t\t(effects
\t\t\t\t(font
\t\t\t\t\t(size 1.27 1.27)
\t\t\t\t)
\t\t\t\t(hide yes)
\t\t\t)
\t\t)
\t\t(property "Description" ""
\t\t\t(at {x} {y} 0)
\t\t\t(effects
\t\t\t\t(font
\t\t\t\t\t(size 1.27 1.27)
\t\t\t\t)
\t\t\t\t(hide yes)
\t\t\t)
\t\t)
{pin_block}
\t\t(instances
\t\t\t(project "{PROJECT}"
\t\t\t\t(path "/{SHEET_UUID}"
\t\t\t\t\t(reference "{ref}")
\t\t\t\t\t(unit {unit})
\t\t\t\t)
\t\t\t)
\t\t)
\t)'''
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

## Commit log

2026-10-06 tạo board dùng cảm biến sợi quang vừa với hộp plc 179x100x48mm
    [fiberboard-logic.kicad_pcb, fiberboard-logic.kicad_sch]
2026-10-07 thêm các linh kiện bảo vệ nguồn và sửa layout để lắp vào hộp PLC 45x90x40mm 2 hàng giắc
    [fiberboard-logic.kicad_pcb, fiberboard-logic.kicad_sch]
2026-10-07 chia vùng linh kiện để sắp xếp và tránh linh kiện quá dày
    [fiberboard-logic.kicad_pcb, fiberboard-logic.kicad_sch]
2026-10-09 update lại linh kiện để tối ưu thương mại. chuyển sang dùng cảm biến sợi quang rời, không tích hợp trên mạch nữa
    [fiberboard-logic.kicad_pcb, fiberboard-logic.kicad_sch]
